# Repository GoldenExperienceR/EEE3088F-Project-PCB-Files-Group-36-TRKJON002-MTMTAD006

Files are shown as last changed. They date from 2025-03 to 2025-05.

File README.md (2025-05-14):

# EEE3088F-Project-PCB-Files-Group-36-TRKJON002-MTMTAD006

EEE3088F Project Power PCB KiCad Design

## Project Overview

This repository contains the design files for the power PCB subsystem of a micro mouse robot, a project undertaken as part of the EEE3088F course. The power PCB is a crucial component responsible for providing and managing power for the entire micro mouse system, enabling its autonomous navigation capabilities.

## Project Requirements

The power PCB design is required to meet the following specifications:

* Operate up to 4 motors bidirectionally. These include 2x brushed DC motors which could each draw 200mA at the highest voltage of a 1S1P battery. The other 2x motors are for the auxiliary connection and need to operate 500mA each.
* Place an INA219 for monitoring the battery on the I2C Bus and configure it correctly with respect to the hardware (cannot have BOTH A0 AND A1 on GND).
* Charge the battery from the 9V input pin.
* Have two charging modes for a higher and lower charging current for the battery (200mA ±100mA, and approximately 600mA±100mA from the battery perspective).
* Integrate USB C and get 9V out of the USB Host.
* Provide 2x External Load Switching at 1A each (High Side connected to your 5V).
* Provide a 3v3 5% accuracy (300mA max) and 5V Out 5% accuracy (1.5A max).
* Provide an ON/OFF switch. **OFF state:** battery draw <30uA. **ON state:** can provide your robot peak current of 2A. The switch needs to shut down 5V and 3V3.

## Repository Structure

This repository utilizes the following branches to manage the project's development:

* **main:** This branch contains the first iteration of the PCB design.
* **jonathans\_branch:** This branch includes separate modifications that were developed and subsequently merged into the `main` branch.
* **design2:** This branch represents the culmination of all changes made throughout the project and contains the final design of the power PCB. For the latest and final version of the design, please refer to this branch.

## Cloning Instructions
To obtain the latest version of the power PCB design, you can clone the `design2` branch directly using the following command:

```bash
git clone -b design2 [https://github.com/GoldenExperienceR/EEE3088F-Project-PCB-Files-Group-36-TRKJON002-MTMTAD006.git](https://github.com/GoldenExperienceR/EEE3088F-Project-PCB-Files-Group-36-TRKJON002-MTMTAD006.git)

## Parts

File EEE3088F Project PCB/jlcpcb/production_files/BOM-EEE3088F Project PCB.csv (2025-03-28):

Comment | Designator | Footprint | LCSC | Quantity
TPS22965DSGR | U8,U9 | SON50P200X200X80-9N | C122837 | 2
TPS22918 | U5 | SOT-23-6 | C131941 | 1
8K | R_PROG_2 | RESC3115X65N | C1488 | 1
220uF | C10 | CAPC2012X140N | C15008 | 1
0.1uF | C16,C18,C20 | CAPC2012X140N | C1525 | 3
10uF | C21,C3,C5,C7 | CAPC1005X55N | C15525 | 4
INA219AxD | U3 | SOIC-8_3.9x4.9mm_P1.27mm | C1574856 | 1
1uF | C17 | CAPC3216X180N | C1592 | 1
TYPE-C-31-M-12 | J2 | HRO_TYPE-C-31-M-12 | C165948 | 1
0.01uF | C1,C6 | CAPC2012X140N | C1710 | 2
300 | R7 | RESC3115X65N | C17617 | 1
10k | R4 | RESC3115X65N | C17902 | 1
10 | R10,R5,R9 | RESC3115X65N | C17903 | 3
1uF | C11,C12,C13,C14,C15,C8 | CAPC3216X180N | C1848 | 6
22uF | C9 | CAPC2012X140N | C1859 | 1
2.2uF | C2,C4 | CAPC1608X90N | C23630 | 2
74LVC1G04SE-7 | IC1 | 74LVC1G04SE-7 | C264081 | 1
74LVC2G66DP | S1 | 74LVC2G66DP | C282354 | 1
MBR230LS | D1 | D_SOD-123F | C391533 | 1
2k | R_PROG_1 | RESC3115X65N | C4109 | 1
2200 | R8 | RESC3115X65N | C4190 | 1
3.3k | R1,R2 | RESC3115X65N | C4211 | 2
1k | R3 | RESC3115X65N | C4410 | 1
DRV8833PWR | U1,U2 | SOP65P640X120-16N | C50506 | 2
LM7805_TO220 | U10 | TO-220-3_Vertical | C7588528 | 1
SX1308 | U7 | SOT-23-6 | C78162 | 1
MIC5504-1.2YM5 | U6 | SOT-23-5 | C88419 | 1
22uH | L1 | SMNR5040-220MT | C9391 | 1
CH224K | U4 | SSOP-10-1EP_3.9x4.9mm_P1mm_EP2.1x3.3mm | C970725 | 1
JST PH 2.00mm connector | J1 | JST_PH_S2B-PH-K_1x02_P2.00mm_Horizontal |  | 1
2x16 (2.54mm pin pitch) pin header | am1 | PinHeader_2x16_P2.54mm_Vertical |  | 1
TC4056A. | U11 | SOIC127P600X175-9N |  | 1
0.22u | C19 | CAPC2012X140N |  | 1
SS12D07VG5 087 | SW1 | SS-12D10G5_XKB |  | 1

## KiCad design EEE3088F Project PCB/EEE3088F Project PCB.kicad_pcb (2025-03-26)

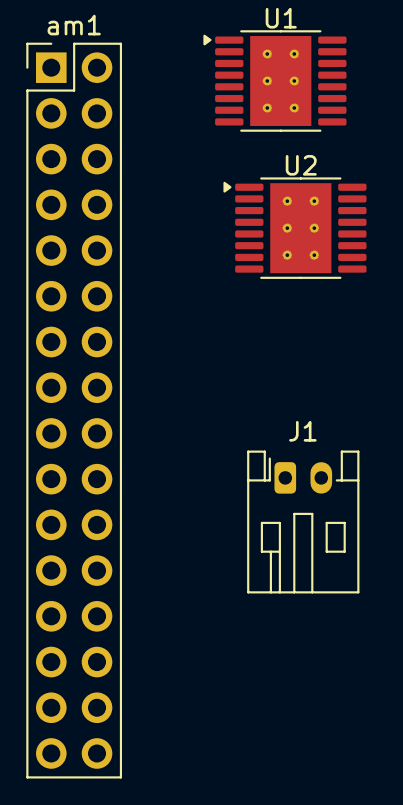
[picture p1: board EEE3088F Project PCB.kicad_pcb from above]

Board: 2 copper layers, 4 parts (0 on the bottom side), 4 nets, no tracks yet.

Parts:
J1: JST PH 2.00mm connector; JST_PH_S2B-PH-K_1x02_P2.00mm_Horizontal
U1, U2: DRV8833PWP; HTSSOP-16-1EP_4.4x5mm_P0.65mm_EP3.4x5mm_Mask2.46x2.31mm_The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
am1: 2x16 (2.54mm pin pitch) pin header; PinHeader_2x16_P2.54mm_Vertical

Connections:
/GND: J1.2, am1.19, am1.23
/Vcc: J1.1, am1.14
unnamed: U1.13 (GND), U1.17 (GND)
unnamed: U2.13 (GND), U2.17 (GND)

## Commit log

2025-03-21 intial commit
    [EEE3088F Project PCB.kicad_pcb, EEE3088F Project PCB.kicad_sch]
2025-03-22 resistor in series with a LED
    [EEE3088F Project PCB.kicad_sch]
2025-03-22 resistor in parallel
    [EEE3088F Project PCB.kicad_sch]
2025-03-23 2x16 pin connector & JST PH 2.00 connector
    [EEE3088F Project PCB.kicad_sch]
2025-03-25 added pin net labels to connectors
    [EEE3088F Project PCB.kicad_pcb, EEE3088F Project PCB.kicad_sch]
2025-03-25 added a calaculations section, and my motor driver circuit
    [BOM-EEE3088F Project PCB.csv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]
2025-03-25 adjusted layout slightly
    [EEE3088F Project PCB.kicad_sch]
2025-03-26 completed power module
    [EEE3088F Project PCB.kicad_sch]
2025-03-26 Added Current sensor INA219
    [EEE3088F Project PCB.kicad_sch]
2025-03-26 Added current sensor
    [EEE3088F Project PCB.kicad_sch]
2025-03-27 corrected sensor design and relabelled Vcc label to Battery
    [EEE3088F Project PCB.kicad_sch]
2025-03-27 added footprints to all motor driver components
2025-03-28 added usb c integration with footprints
    [EEE3088F Project PCB.kicad_sch]
2025-03-28 added regulatores, updated outputs, added on/off switch
    [EEE3088F Project PCB.kicad_sch]
2025-03-28 adjusted shunt resistance
    [EEE3088F Project PCB.kicad_sch]
2025-03-28 finished circuit
    [BOM-EEE3088F Project PCB.csv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]
2025-05-14 Update README.md
    Added information about project requirements, the repos' structure and how clone the repo to obtain the latest PCB design.
